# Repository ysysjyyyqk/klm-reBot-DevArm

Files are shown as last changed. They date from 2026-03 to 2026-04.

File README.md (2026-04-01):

# 🦾 reBot-DevArm: Open Source Robotic Arm for All Developers

<p align="center">
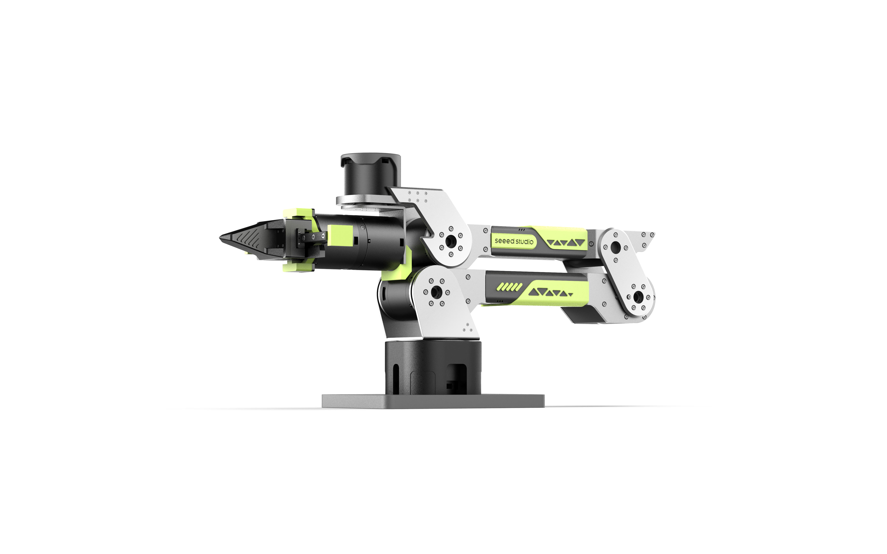
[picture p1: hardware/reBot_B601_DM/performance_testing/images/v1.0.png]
reBot-DevArm Banner
  
</p>

<p align="center">
    <!-- Replaced with CC BY-NC-SA 4.0 badge, explicitly indicating non-commercial use -->
    <a href="./LICENSE">
    
    </a>
    
    
    
    
</p>

<p align="center">
  <strong>100% Fully Open Source · Embodied AI · Hardware-Software Integration · Free for Personal/Education · Commercial Use Requires Authorization</strong>
</p>

<p align="center">
  <strong>
    <a href="./README_zh.md">简体中文</a> &nbsp;|&nbsp;
    <a href="./README.md">English</a> &nbsp;|&nbsp;
    <a href="./README_JP.md">日本語</a>&nbsp;|&nbsp;
    <a href="./README_Fr.md">français</a>&nbsp;|&nbsp;
    <a href="./README_es.md">Español</a>
  </strong>
</p>

<p align="center">
<a href="https://discord.gg/AbGuqJhDpQ">
    </a>
<a href="https://wiki.seeedstudio.com/robotics_page/">  
    </a>
</p>

## 📖 Introduction

**reBot-DevArm (reBot Arm B601 DM and reBot Arm B601 RS)** is a robotic arm project dedicated to lowering the barrier to learning Embodied AI. We focus on **"True Open Source"** — not just the code, we unreservedly open source everything:
- 🦾 **Two versions of the robotic arm**：We will provide all open-source files for two versions of the robotic arm with the same appearance: **Robostride** and **Damiao**.
- 🛠️ **Hardware Blueprints**: Source files for sheet metal parts and 3D printed parts.
- 🔩 **BOM List**: Detailed down to the specifications and purchase links for every single screw.
- 💻 **Software & Algorithms**: Python SDK, ROS1/2, Isaac Sim, LeRobot, etc.

## Build Your Own reBot Arm

- We offer five kit options:
  - **Arm Body Motor Kit**: Includes only motors and wiring harnesses for the robotic arm.
  - **Arm Body Structural Kit**: Includes only mechanical structural components.
  - **Gripper Complete Kit**: Includes motors, wiring harnesses and structural components for the gripper.
  - **Full Kit**: Includes the complete set of the robotic arm body and gripper.
  - **Pre‑assembled Robotic Arm**: Fully assembled finished robotic arm.

You may purchase the remaining parts from the SeeedStudio Store based on the components you already have (expected availability: April 15, 2026).

[You can leave your information here, and we will send you the limited pre-order link in advance.](https://forms.gle/1MwdVKUqkuGu3C7L7)

## Getting Your Own reBot Arm

- We offer five versions of kits
  - **Arm Body Motor kit** for the robotic arm including only motors and wiring harnesses.
  - **Arm Body structural kit** containing only mechanical structural components. 
  - **Arm Gripper Complete kit** Motor, wiring and structural components of Gripper. 
  - **Complete kit** with the robotic arm plus gripper. 
  - **Assembled Arm** Pre-assembled robotic arm.

  You may purchase the remaining parts from the SeeedStudio bazaar (ETA 04.15.2026) based on the materials you already have.

  You may leave your information here, and we will send you the limited pre-order link in advance.

## 🗺️ Roadmap & Status

We are committed to continuously maintaining and adapting to mainstream robot development ecosystems. Below is our current adaptation progress and planned release schedule:

### reBot Arm B601 DM
| Supported Ecosystem | Status | Description / Estimated Release Date | Related Documentation |
| :--- | :---: | :--- | :--- |
| **Basic Motor Usage** | ✅ Completed | Basic motion control and API encapsulation | [Damiao Technology](https://wiki.seeedstudio.com/cn/damiao_series/) |
| **Open-Sourcing of the New STEP 3D Structural Parts and BOM** | ✅ Completed | STEP files for all parts in the new version, parts BOM, and reference prices for all machined components | [reBot Arm B601-DM BOM](./hardware/reBot_B601_DM/readme.md) |
| **Reference for Real Machine Performance Testing** | 🚧 In Progress  | Performance Reference of Robotic Arm under Normal and Extreme Operating Conditions |[Performance Testing](./hardware/reBot_B601_DM/performance_testing/Performance_Testing.md) |
| **Assembly Video** | 🚧 In Progress | Ultra-detailed assembly steps and video | [Expected: 2026.04.10] |
| **ROS2 (Humble)** | 🚧 In Progress  | Core drivers have been completed, and MoveIt2 is currently being optimized | [Expected: 2026.04.10] |
| **Python SDK** | 🚧 In Progress  |  | [Expected: 2026.04.10] |
| **Pinocchio Integration** | 🚧 In Progress  | Adaptation to the Pinocchio framework, enabling forward/inverse kinematics and gravity compensation for the robotic arm | [Expected: 2026.04.10] |
| **Isaac Sim Simulation** | 🚧 In Progress  | Import USD models and enable simulated teleoperation | [Expected: 2026.04.20] |
| **LeRobot Integration** | 🚧 In Progress  | Adaptation to the Hugging Face LeRobot training framework | [Expected: 2026.04.30] |
| **Gradual Updates of the Latest Algorithms** | ⏳ Planned | Mainstream algorithms will be updated progressively | Ongoing |
| **Launch of a Series of Completely Free Courses** | ⏳ Planned | Mainstream algorithms will be updated progressively | Ongoing |

### reBot Arm B601 RS

| Supported Ecosystem | Status | Description / Estimated Release Date | Related Documentation |
| :--- | :---: | :--- | :--- |
| **Basic Motor Usage** | ✅ Completed | Basic motion control and API encapsulation | [Robstride](https://wiki.seeedstudio.com/cn/robstride_control/) |
| **Open-Sourcing of the New STEP 3D Structural Parts and BOM** | 🚧 In Progress | STEP files for all parts in the new version, parts BOM, and reference prices for all machined components | Expected [2026.04.31] |
| **Assembly Video** | 🚧 In Progress | Ultra-detailed assembly steps and video | [Expected 2026.05.10] |
| **ROS2 (Humble)** | ⏳ Planned | Core drivers have been completed, and MoveIt2 is currently being optimized | [Expected 2026.05] |
| **LeRobot Integration** | ⏳ Planned | Adaptation to the Hugging Face LeRobot training framework | [Expected 2026.05] |
| **Pinocchio Integration** | ⏳ Planned | Adaptation to the Pinocchio framework, enabling forward/inverse kinematics and gravity compensation for the robotic arm | [Expected 2026.05] |
| **Isaac Sim Simulation** | ⏳ Planned | Import USD models and enable simulated teleoperation | [Expected 2026.05] |
| **Gradual Updates of the Latest Algorithms** | ⏳ Planned | Mainstream algorithms will be updated progressively | Ongoing |
| **Launch of a Series of Completely Free Courses** | ⏳ Planned | Mainstream algorithms will be updated progressively | Ongoing |

---

### 🎓 Full-Stack Robotics Ecosystem
reBot-DevArm is not just a robotic arm, but a robotics learning community. We share the following general tutorials for free:

#### 🖥️ Edge Computing & Master Control
*    —— **AI Inference & Compute Core**
*    —— **General Linux Development Environment**
*    —— **Low-power Wireless Control Node**

#### 📡 Sensors & Peripherals
*   **🚗 Motors & Servos**: [Damiao / Gogo / Robstride / Mita / Feite / Fashion Star](https://wiki.seeedstudio.com/robotics_page/)
*   **👁️ Visual Perception**: [Depth Cameras / LiDAR / Vision Algorithms](https://wiki.seeedstudio.com/robotics_page/)
*   **👂 Auditory Interaction**: [ReSpeaker Mic Arrays / Speech Recognition](https://wiki.seeedstudio.com/ReSpeaker_Mic_Array_v2.0/)
*   **🧭 Motion & Attitude**: [IMU (6-axis/9-axis) / Gyroscopes / Magnetometers](https://wiki.seeedstudio.com/Sensor/IMU/)
*   **🤖 Comprehensive Kits**: [More Robotics Sensors & Driver Examples](https://wiki.seeedstudio.com/robotics_page/)

> 👉 **[Click to Enter Wiki Knowledge Base](https://wiki.seeedstudio.com/)** (All tutorials are free to view)

---

## ⚙️ Hardware Specifications

reBot-DevArm is designed for desktop Embodied AI applications, balancing payload capacity with flexibility.

| Parameter | reBot Arm B601-DM |
| :--- | :--- |
| **Recommended Continuous Payload** | Less than 1.5 kg within 70% of arm reach workspace |
| **Recommended Payload** | **1.5 kg** |
| **Max Reach** | **650 mm** |
| **Weight** | Approx. 4.5 kg |
| **Repeatability** | < 0.2 mm |
| **Degrees of Freedom (DOF)** | 6 DOF + 1 Gripper (Open source CAN servo gripper and joint motor gripper coming soon) |
| **Supported Platforms/Ecosystems** | ROS1, ROS2, LeRobot, Pinocchio, Isaac Sim, Python SDK |
| **Supply Voltage** | DC 24V |

## 🙌 References & Acknowledgments
The path of open source is never lonely. The birth of the reBot-DevArm project would not be possible without the full support of Seeed Studio, the global open source community, and excellent hardware partners. We pay our highest respects to the following projects and teams:

### 🌍 Ecosystem & Software Support
*   **[Seeed Studio](https://www.seeedstudio.com/)** - Providing comprehensive hardware supply chain and technical support.
*   **[Hugging Face LeRobot](https://github.com/huggingface/lerobot)** - An excellent end-to-end robot learning framework.
*   **[NVIDIA Isaac Sim](https://developer.nvidia.com/isaac/sim)** - A powerful robot simulation and synthetic data platform.

### ⚙️ Core Hardware Partners
Thanks to the following manufacturers for providing high-performance motor and actuator solutions:
*   **[Damiao Technology](https://www.damiaokeji.com/)**
*   **[Robstride](https://robstride.com/)**
*   **[Fashion Star](https://fashionrobo.com/)**

### 💡 Inspiration
This project is deeply inspired by the following excellent open source projects:
*   **[SO-ARM100](https://github.com/TheRobotStudio/SO-ARM100/tree/main)**
*   **[Mobile ALOHA](https://github.com/tonyzhaozh/aloha)**
*   **[Dummy-Robot (Zhihui Jun)](https://github.com/peng-zhihui/Dummy-Robot)**
*   **[OpenArm](https://openarm.dev/)**
*   **[I2RT](https://i2rt.com/)**
*   **[TRLC-DK1](https://github.com/robot-learning-co/trlc-dk1)**

### 🎃 Prototype Contributors
- **SeeedStudio AI Robotics Team's**: Yaohui Zhu (yaohui.zhu@seeed.cc)
- **SeeedStudio STU**: Wentao Dong
- **SeeedStudio STU**: Weiwei Xu
- **SeeedStudio Purchasing Department**: Fengqun Peng

### 👥 Contributors

## Our Top Contributors 
<p align="center"><a href="https://github.com/Seeed-Projects/reBot-DevArm/graphs/contributors">
  
</a></p>

*Coming soon... Welcome to submit PRs to become a contributor!*

## Star History

Star History Chart (https://www.star-history.com/#Seeed-Projects/reBot-DevArm&type=date&legend=top-left)

# reBot-DevArm Project License
Copyright (c) [2025] [Seeed Studio]

This work is licensed under the **Creative Commons Attribution-NonCommercial-ShareAlike 4.0 International License**.
To view a copy of this license, visit: http://creativecommons.org/licenses/by-nc-sa/4.0/

--------------------------------------------------------------------------------

## Rights and Restrictions Statement

The core purpose of this open-source project is to promote knowledge sharing and enable developers and enthusiasts to access and learn cutting-edge robotic arm technologies at minimal cost. We provide completely free and publicly available documentation and video tutorials to help users get started quickly, conduct in-depth research, and jointly promote the popularization and practical application of robotics.

### I. Non-Commercial Use Policy

All open-source content of this project is fully available for personal learning, research, and non-commercial use. Individual users are allowed to:

* View and study the project’s open-source documentation, code, and tutorials;
* Modify and debug the open-source content for personal learning and research purposes;
* Assemble robotic arms for personal use or conduct secondary development based on the open-source content for non-commercial purposes.

### II. Commercial Use Policy

We actively encourage and support developers, robotics enthusiasts, and third-party platforms to carry out secondary development based on the reBot robotic arm and promote real-world applications. The following outlines permitted and prohibited commercial activities:

#### (1) Permitted Commercial Activities

We respect every developer’s efforts and legitimate earnings. If you purchase the reBot B601 series robotic arm from Seeed and contribute your own work, you may commercialize the results of your efforts, including but not limited to:

* Developing application-oriented software systems and promoting or selling them commercially;
* Creating structured educational courses (online/offline) and offering paid training or knowledge services;
* Conducting offline education, training, and technology outreach activities worldwide;
* Other commercial activities that contribute to the open-source community, knowledge dissemination, and real-world application of robotics technology.

For the above compliant commercial activities, you are welcome to contact us. We will provide commercial authorization, implementation support, and promotional assistance. We may also publicly announce your authorization to help your project succeed.

#### (2) Prohibited Commercial Activities

It is prohibited to make minor modifications to this project’s product, replace IP, logos, or related identifiers, and sell it under a self-owned brand. Such actions do not constitute substantial technical innovation and do not benefit developer growth, the open-source community, or the project itself. These behaviors are considered violations, and we reserve the right to take action.

### III. Collaboration & Contact

We hope to collaborate with all developers and partners within a compliant framework to promote the maturity and deployment of the reBot robotic arm project. For individuals and organizations interested in bringing real-world robotic applications to life, we offer:

* Commercial licensing and intellectual property compliance support;
* Assistance in promoting project solutions;
* Custom development services for robotic arms and related solutions;
* Joint R&D and co-development opportunities.

If you are interested in commercial collaboration or have related needs, please feel free to contact us. Let’s work together to advance the adoption and industrialization of robotics technology.

## ☎ Contact Us
- **Open‑Source Progress & Technical Support**-Yaohui: yaohui.zhu@seeed.cc
- **Future Collaboration & Customization**-Elaine: elaine.wu@seeed.cc

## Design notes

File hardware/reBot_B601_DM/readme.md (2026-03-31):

# 🤖 reBot DevArm Open-Source Hardware Description

<p align="center">
  reBot-DevArm Banner
</p>

<p align="center">
  <strong>
    <a href="./readme_zh.md">简体中文</a> &nbsp;|&nbsp;
    <a href="./readme.md">English</a> &nbsp;|&nbsp;
    <a href="./readme_jp.md">日本語</a>&nbsp;|&nbsp;
    <a href="./readme_fr.md">français</a>&nbsp;|&nbsp;
    <a href="./readme_es.md">Español</a>
  </strong>
</p>

The current BOM is the component list for the **reBot Arm B601 DM** robotic arm, which uses the **Damiao 43 series motors**. Another version, the **reBot Arm B601 RS** robotic arm, uses **RobStride motors**. [Please see the list here](../reBot_B601_RS/README.md)

# 📦 File Structure

* `3D_Printed_Parts/`: STEP files for all 3D-printed parts.
* `Metal_Parts/`: STEP files for all metal machined parts.
* `Purchased_Parts/`: STEP files for all purchased parts.
* `reBot_B601_DM_v1.0_20260331.step`: Complete robotic arm assembly file.

# 📊 Bill of Materials (BOM)

> [!WARNING]
> Hereby declared: the published BOM does **not** represent the final version shipped by Seeed. This `v1.0` open-source version is intended to help developers reproduce the design themselves with the lowest possible cost, and therefore reduces some unnecessary detail-related expenses. The final version shipped by Seeed will include details that increase cost, such as laser-engraved anti-error markings on metal parts, replacement of some 3D-printed parts with metal parts for durability, clearance and machining precision adjustments based on the tolerances of metal processing factories (a balance between precision and cost), special customization of wire harnesses (for example, adding braided rope protection), and other detail optimizations. However, the structural configuration remains the same.

---

## 🖨️ 3D-Printed Parts

| Part Description | Image | File Name | Material | Quantity | Notes |
|---|---|---|---|---|---|
| Robotic arm base platform |  | `01_BASE_Plate.step` | Bambu ABS Black | 1 | 0.4 nozzle, 0.2 layer height, 30% infill |
| Robotic arm base |  | `01_BASE_Link.step` | Bambu ABS Black | 1 | 0.4 nozzle, 0.2 layer height, 30% infill |
| Upper arm left filler |  | `01_Upper_Arm_Fuller_L.step` | Bambu PLA Black and Green | 1 | 0.4 nozzle, 0.2 layer height, 15% infill |
| Upper arm right filler |  | `01_Upper_Arm_Fuller_R.step` | Bambu PLA Black and Green | 1 | 0.4 nozzle, 0.2 layer height, 15% infill |
| Upper arm middle filler |  | `01_Upper_Arm_Fuller_M.step` | Bambu ABS Black | 1 | 0.4 nozzle, 0.2 layer height, 30% infill |
| Upper arm horizontal limit block |  | `01_Upper_Arm_Limit.step` | Bambu ABS Black | 1 | 0.4 nozzle, 0.2 layer height, 30% infill |
| Robotic arm handle |  | `01_Arm_Handle.step` | Bambu ABS Black | 1 | 0.4 nozzle, 0.2 layer height, 30% infill |
| Forearm left filler |  | `01_Lower_Arm_Filler_L.step` | Bambu PLA Black and Green | 1 | 0.4 nozzle, 0.2 layer height, 15% infill |
| Forearm right filler |  | `01_Lower_Arm_Filler_R.step` | Bambu PLA Black and Green | 1 | 0.4 nozzle, 0.2 layer height, 15% infill |
| Forearm middle filler |  | `01_Lower_Arm_Filler_M.step` | Bambu ABS Black | 1 | 0.4 nozzle, 0.2 layer height, 30% infill |
| Upper arm decorative cover |  | `01_Upper_Arm_Cover.step` | Bambu PLA Green | 1 | 0.4 nozzle, 0.2 layer height, 15% infill |
| Forearm decorative cover |  | `01_Lower_Arm_Cover.step` | Bambu PLA Green | 1 | 0.4 nozzle, 0.2 layer height, 15% infill |
| Motor No. 5 protective cover |  | `01_Motor_Cover.step` | Bambu ABS Black | 1 | 0.4 nozzle, 0.2 layer height, 30% infill |
| Gripper horizontal limit |  | `01_Lower_Arm_Limit.step` | Bambu PLA Green | 1 | 0.4 nozzle, 0.2 layer height, 15% infill |
| Gripper slider filler bracket |  | `01-Rail-Bracket.step` | Bambu PLA Green | 1 | 0.4 nozzle, 0.2 layer height, 15% infill |
| Gripper |  | `01_Finger.step` | Bambu ABS Black | 2 | 0.4 nozzle, 0.2 layer height, 45% infill |
|  | `Reference price` | Average **50 $** |  |  | Price may vary slightly depending on printing material prices and factory printing time |

### 🧩 Printing Recommendations

- Layer height: 0.2 mm
- Nozzle: 0.4 mm
- Supports: add as needed
- Materials: parts that need to withstand heat and certain force use ABS material with 30% to 80% infill, and may also be changed to nylon / carbon-fiber-reinforced materials; appearance/decorative parts use PLA with 15% infill.
- Recommended materials for load-bearing parts:

---

## 🔩 Metal Machined Parts

> [!WARNING]
> Some parts that can be replaced with 3D printing are indicated in the notes below, which can further greatly reduce costs.

| Part Description | Image | File Name | Material | Quantity | Manufacturing Process | Notes |
|---|---|---|---|---|---|---|
| Motor 1 bearing mounting position |  | `02_Base_Motor_Shim.step` | Aluminum Alloy 5052 | 1 | CNC | Can be replaced with 3D-printed ABS with increased infill to reduce cost |
| Motor 1 rotating shaft |  | `02_Arm_Yaw_Limit.step` | Aluminum Alloy 5052 | 1 | CNC | Adds yaw angle motion limit |
| Front spacer for motors 2-5 |  | `02_Motor_Front_Spacer.step` | Aluminum Alloy 5052 | 4 | CNC | Can be replaced with 3D-printed ABS, 30% infill, to reduce cost |
| Rear spacer for motors 2-4 |  | `02_Motor_Back_Spacer.step` | Aluminum Alloy 5052 | 3 | CNC |  |
| Rear flange for motors 2-4 |  | `02_FLANGE.step` | Aluminum Alloy 5052 | 3 | CNC |  |
| Wrist motor 5 base |  | `02_Wrist_Bracket.step` | Aluminum Alloy 5052 | 1 | CNC |  |
| Gripper connector A |  | `02_Gripper_Connector_A.step` | Aluminum Alloy 5052 | 1 | CNC |  |
| Gripper connector B |  | `02_Gripper_Connector_B.step` | Aluminum Alloy 5052 | 1 | CNC |  |
| Gripper slider metal bracket |  | `02_Slider_Bracket.step` | Aluminum Alloy 5052 | 1 | CNC | Can be replaced with 3D-printed ABS with increased infill to reduce cost, but not recommended for long-term use |
| Slider and gripper connector |  | `02_Slider_Extension.step` | Aluminum Alloy 5052 | 2 | CNC |  |
| Upper and lower arm joint connector left |  | `02_Lower_Upper_Link_L.step` | Aluminum Alloy 5052 | 1 | CNC |  |
| Upper and lower arm joint connector right |  | `02_Lower_Upper_Link_R.step` | Aluminum Alloy 5052 | 1 | CNC |  |
| Forearm and wrist joint connector left |  | `02_Lower_Wrist_Link_L.step` | Aluminum Alloy 5052 | 1 | CNC |  |
| Forearm and wrist joint connector right |  | `02_Lower_Wrist_Link_R.step` | Aluminum Alloy 5052 | 1 | CNC |  |
| Gear connector |  | `02_Gear_Connector.step` | Aluminum Alloy 5052 | 1 | CNC | For low load, 3D-printed ABS with 80% infill can be used to reduce cost; for high load, CNC metal machining is recommended |
| Rack |  | `02_Rack.step` | Aluminum Alloy 5052 | 2 | CNC |  |
| Link 1 |  | `03-Link1.step` | Aluminum Alloy 5052 | 1 | CNC + Sheet Metal |  |
| Link 2 |  | `03-Link2.step` | Aluminum Alloy 5052 | 2 | CNC + Sheet Metal |  |
| Link 3 left |  | `03-Link3_L.step` | Aluminum Alloy 5052 | 1 | CNC + Sheet Metal |  |
| Link 3 right |  | `03-Link3_R.step` | Aluminum Alloy 5052 | 1 | CNC + Sheet Metal |  |
| Link 5 |  | `03-Link5.step` | Aluminum Alloy 5052 | 1 | CNC + Sheet Metal |  |
| Multiple market reference price |  | Average **250 $** |  |  |  | Price may vary slightly due to fluctuations in aluminum 5052 cost, machining precision requirements, factory lead time, etc. |

### 🧩 Machining Instructions

- Critical dimensional tolerance: ±0.02 mm, GB/T1840-M;
- Surface treatment: anodizing / sandblasting
- Mating parts are recommended to use H7 / interference fit

---

## 🛒 Purchased Parts (Standard Parts)

> [!WARNING]
> Since everyone will need to assemble and tighten the screws themselves, standard hex socket screws have been selected. After prolonged operation, the screws may loosen, which will affect the precision of the robotic arm. For this reason, you are required to purchase additional hot melt glue to perform thread locking on the screws at each joint.

If you have a power drill or similar tools, you may choose to buy lock washers or thread-locking screws instead. However, **it is extremely important** that you use the lowest torque setting when using an electric screwdriver to avoid thread stripping, which will result in irreversible damage.

| Name | Specification / Model | Quantity | Reference Price | Notes |
|---|---|---|---|---|
| Brushless motor | DM4310(V4) | 4 | 120 $/unit | [SeeedStudio](https://www.seeedstudio.com/DIP-Servo-Motor-24V-120RPM-Brushless-98-9mm-4P-L56-W56-H46mm-p-6660.html) |
| Brushless motor | DM4340P(V4) | 3 | 175 $/unit |  [SeeedStudio](https://www.seeedstudio.com/DM4340P-Actuator-p-6663.html)  |
| CAN-USB driver board |  | 1 | 15 $/unit | [SeeedStudio](https://www.seeedstudio.com/DM-CAN-USB-Driver-Borad-p-6706.html) |
| Bearing | 6707ZZ | 1 | 13 $/unit | [Amazong](https://www.amazon.com/uxcell-35x44x5mm-Shielded-Precision-Lubricated/dp/B0D6WBMW3F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) |
| Bearing | 6803ZZ | 3 | 13 $/unit | [Amazong](https://www.amazon.com/uxcell-17x26x5mm-Shielded-Precision-Lubricated/dp/B0D54JSWBZ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) |
| Bearing | AXK5578 | 1 | 12 $/unit | [Amazong](https://www.amazon.com/PZRT-AXK5578-Thrust-Bearings-Washers/dp/B0B3M3RZGW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) |
| Linear rail | MGN9-170mm | 1 | 23 $/unit | [Amazong](https://www.amazon.com/uxcell-Sliding-Carriage-Bearing-Printers/dp/B0D54L45WM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) |
| Slider block | MGN9 | 2 | 10 $/unit | [Amazong](https://www.amazon.com/uxcell-Bearing-Sliding-Carriage-Anti-Fall/dp/B0D9QBQDKB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) |
| Gear | Module 1, boss type, 16 teeth, 6 mm bore | 1 | 44$/unit | [Amazong](https://www.amazon.com/Module-15-Teeth-Finished-Perforation/dp/B0GDSR1LKM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)  |
| Silicone pad | 30*9*2mm | 1 | 10 $ | [Amazong](https://www.amazon.com/Self-Adhesive-Anti-Sliding-Anti-Scratch-Protectors-Appliances/dp/B0F9KVYXFZ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) |
| Copper standoff | M4x50mm | 4 | 8 $ | [Amazong](https://www.amazon.com/Female-Standoff-Quadcopter-Computer-Circuit/dp/B09V2CYDMG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) |
| Screw | M3*22mm screw | Several |  | [Amazong](https://www.amazon.com/METERXITY-50-Pack-Stainless-Threaded-Fasteners/dp/B0FLYG7WZ7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)  |
| Screw | M4*16mm screw | Several |  | [Amazong](amazon.com/BNUOK-120pcs-Stainless-Threads-Spanner/dp/B0DYNFFB7Q/ref=sr_1_9?crid=W94HLTGLCH57&dib=eyJ2IjoiMSJ9.jg07IMpJdHhW8vR9Ewx53UNnQs_QkpENya6ZqIQWoB6rsXjPLmfWMgAytRy7neNPJJHQzVyP9H7FO5sm9KN9I34nKUQsLRZAG48Rs2rSHwlh2mpA2IPlezHLRlvLN49IIbiHgk5Y63iPwAaxKT27sG3dhyXpf-EABXWIlgUu0FBQ3IIA5kiQDccrsIPN06nR6XBFnNeTu1ogpvhiaZsK7R-VRXcFAsrQvOc4tnzXLlTSM68gR8hBmGYZtQUoOJrRo93U1xfGf7kODnnOqUBWI3VhQIMgnl8Rtt4pl3H7IK0._jHfn0N3UQ0z_FJlv4C8jBXiadkqdO-IHWJzQ3xlm0w&dib_tag=se&keywords=M4*16mm+screw&qid=1774772422&s=industrial&sprefix=m4+16mm+screw%2Cindustrial%2C364&sr=1-9)  |
| Screw | M3*8mm set screw | 5 | 5$ | [Amazong](https://www.amazon.com/Headless-Internal-Stainless-Concave-External/dp/B0D8TGXG9D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)  |
| Screw | M3*22mm countersunk screw | Several |  |  [Amazong](https://www.amazon.com/Countersunk-DIN7991-Stainless-Threaded-Fasteners/dp/B0CG1PV6SH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) |
| Screw | M3*8mm countersunk screw | Several |  | [Amazong](https://www.amazon.com/Countersunk-DIN7991-Stainless-Threaded-Fasteners/dp/B0CG1PV6SH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)  |
| Screw | M3*16mm countersunk screw | Several |  |[Amazong](https://www.amazon.com/Countersunk-DIN7991-Stainless-Threaded-Fasteners/dp/B0CG1PV6SH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) |
| Screw | M3*12mm self-tapping screw | Several |  | [Amazong](https://www.amazon.com/Countersunk-DIN7991-Stainless-Threaded-Fasteners/dp/B0CG1PV6SH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)  |
| Dowel pin | M4*8mm | Several |  | [Amazong](https://www.amazon.com/Countersunk-DIN7991-Stainless-Threaded-Fasteners/dp/B0CG1PV6SH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)  |
| Dowel pin | M4*12mm | Several |  | [Amazong](https://www.amazon.com/Countersunk-DIN7991-Stainless-Threaded-Fasteners/dp/B0CG1PV6SH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)  |
| Screwdriver set | Hex key set | 1 | 16$  | [Amazong](amazon.com/Amazon-Basics-Ratcheting-Electronics-Screwdriver/dp/B07V4TFWFZ/ref=sr_1_2?crid=ADAY70RZDSLN&dib=eyJ2IjoiMSJ9.jcLL4o6IXTnPlPfTTzbCZCBuZx2sLkvdUQCwlL58aq__GOyLxVPnwLI0mvGptba_HeVz6ctLQ_ziQw56BMDH9IOaw-4PVJGMktQM74mWficwggm3ckDGyAH-agN_zkB3K0_W-wrS56jfcMYFbZSWhWxr-iSOC4sdXwMGlt4rYGtenyn9yAFYBIHqjU2El5_OAKuspsrF0yQvfyfQPQHs46SClWN8zlSemGVZRuVSU26f0f9yApF6BfWHANKNNhT0Mfb6bQ8oM2XUMvwaazrrKoHeTARuoflVaVZvMU776bs.r8gy_gMINEy0qy4JyK--z-IbPZEv-SWeMGohOOE7M60&dib_tag=se&keywords=Screwdriver+set&qid=1774772499&s=industrial&sprefix=screwdriver+set+%2Cindustrial%2C374&sr=1-2)  |
| Custom required | XT30 2+2 350mm | 2 | 4 $/cable | Both ends angled |
| Custom required | XT30 2+2 350mm | 1 | 4 $/cable | One angled end and one straight end |
| Custom required | XT30 2+2 200mm | 3 | 4 $/cable | Both ends angled |
| Custom required | XT30 2+2 200mm | 1 | 3 $/cable | Both ends straight |
| Woodworking clamp | 6-inch G clamp | 2 | 20 $/unit | [Amazong](https://www.amazon.com/gp/aw/d/B092J1YW2M/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) |
| Power supply | 24V 14.6A | 1 | 30$ | [Amazong](https://www.amazon.com/MEAN-WELL-LRS-350-24-350-4W-Switchable/dp/B013ETVO12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) |
| Power Cable | 12AWG | 1 | 30 $ | [Amazong](https://www.amazon.com/Pinfox-Universal-Appliance-Replacement-Pigtail/dp/B0F5PW5SJG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) |
| Power Cable | XT30 16awg | 1 | 9 $ | [Amazong](https://www.amazon.com/RioRand-Connector-Pigtail-Silicone-Aircraft/dp/B0FY2ZCR83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) |

---

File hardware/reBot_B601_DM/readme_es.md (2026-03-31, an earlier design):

# 🤖 Descripción del hardware de código abierto reBot DevArm

<p align="center">
  Banner de reBot-DevArm
</p>
<p align="center">
  <strong>
    <a href="./readme_zh.md">简体中文</a> &nbsp;|&nbsp;
    <a href="./readme.md">English</a> &nbsp;|&nbsp;
    <a href="./readme_jp.md">日本語</a>&nbsp;|&nbsp;
    <a href="./readme_fr.md">français</a>&nbsp;|&nbsp;
    <a href="./readme_es.md">Español</a>
  </strong>
</p>

La BOM actual es la lista de componentes del brazo robótico **reBot Arm B601 DM**, que utiliza los **motores de la serie Damiao 43**. Otra versión, el brazo robótico **reBot Arm B601 RS**, utiliza **motores RobStride**. [Consulte la lista aquí](../reBot_B601_RS/README_zh.md)

# 📦 Estructura de archivos

* `3D_Printed_Parts/`: archivos STEP de todas las piezas impresas en 3D.
* `Metal_Parts/`: archivos STEP de todas las piezas metálicas mecanizadas.
* `Purchased_Parts/`: archivos STEP de todas las piezas compradas.
* `reBot_B601_DM_v1.0_20260331.step`: archivo de ensamblaje completo del brazo robótico.

# 📊 Lista de materiales (BOM)

> [!WARNING]
> Por la presente se declara: la BOM publicada **no** representa la versión final enviada por Seeed. Esta versión de código abierto `v1.0` está destinada a ayudar a los desarrolladores a reproducir el diseño por sí mismos con el menor costo posible y, por lo tanto, reduce algunos gastos innecesarios relacionados con detalles. La versión final enviada por Seeed incluirá detalles que aumentan el costo, como marcas antierrores grabadas con láser en las piezas metálicas, reemplazo de algunas piezas impresas en 3D por piezas metálicas para mayor durabilidad, ajustes de holgura y precisión de mecanizado basados en las tolerancias de las fábricas de procesamiento de metal (un equilibrio entre precisión y costo), personalización especial del arnés de cables (por ejemplo, añadiendo protección con malla trenzada) y otras optimizaciones de detalle. Sin embargo, la configuración estructural sigue siendo la misma.

---

## 🖨️ Piezas impresas en 3D

| Descripción de la pieza | Image | File Name | Material | Quantity | Notes |
|---|---|---|---|---|---|
| Plataforma base del brazo robótico |  | `01_BASE_Plate.step` | Bambu ABS Black | 1 | boquilla 0.4, altura de capa 0.2, relleno 30% |
| Base del brazo robótico |  | `01_BASE_Link.step` | Bambu ABS Black | 1 | boquilla 0.4, altura de capa 0.2, relleno 30% |
| Relleno izquierdo del brazo superior |  | `01_Upper_Arm_Fuller_L.step` | Bambu PLA Black and Green | 1 | boquilla 0.4, altura de capa 0.2, relleno 15% |
| Relleno derecho del brazo superior |  | `01_Upper_Arm_Fuller_R.step` | Bambu PLA Black and Green | 1 | boquilla 0.4, altura de capa 0.2, relleno 15% |
| Relleno central del brazo superior |  | `01_Upper_Arm_Fuller_M.step` | Bambu ABS Black | 1 | boquilla 0.4, altura de capa 0.2, relleno 30% |
| Tope horizontal del brazo superior |  | `01_Upper_Arm_Limit.step` | Bambu ABS Black | 1 | boquilla 0.4, altura de capa 0.2, relleno 30% |
| Asa del brazo robótico |  | `01_Arm_Handle.step` | Bambu ABS Black | 1 | boquilla 0.4, altura de capa 0.2, relleno 30% |
| Relleno izquierdo del antebrazo |  | `01_Lower_Arm_Filler_L.step` | Bambu PLA Black and Green | 1 | boquilla 0.4, altura de capa 0.2, relleno 15% |
| Relleno derecho del antebrazo |  | `01_Lower_Arm_Filler_R.step` | Bambu PLA Black and Green | 1 | boquilla 0.4, altura de capa 0.2, relleno 15% |
| Relleno central del antebrazo |  | `01_Lower_Arm_Filler_M.step` | Bambu ABS Black | 1 | boquilla 0.4, altura de capa 0.2, relleno 30% |
| Cubierta decorativa del brazo superior |  | `01_Upper_Arm_Cover.step` | Bambu PLA Green | 1 | boquilla 0.4, altura de capa 0.2, relleno 15% |
| Cubierta decorativa del antebrazo |  | `01_Lower_Arm_Cover.step` | Bambu PLA Green | 1 | boquilla 0.4, altura de capa 0.2, relleno 15% |
| Cubierta protectora del motor n.º 5 |  | `01_Motor_Cover.step` | Bambu ABS Black | 1 | boquilla 0.4, altura de capa 0.2, relleno 30% |
| Tope horizontal de la pinza |  | `01_Lower_Arm_Limit.step` | Bambu PLA Green | 1 | boquilla 0.4, altura de capa 0.2, relleno 15% |
| Soporte de relleno del deslizador de la pinza |  | `01-Rail-Bracket.step` | Bambu PLA Green | 1 | boquilla 0.4, altura de capa 0.2, relleno 15% |
| Pinza |  | `01_Finger.step` | Bambu ABS Black | 2 | boquilla 0.4, altura de capa 0.2, relleno 45% |
|  | `Reference price` | Promedio **50 $** |  |  | El precio puede variar ligeramente según el precio del material de impresión y el tiempo de impresión de la fábrica |

### 🧩 Recomendaciones de impresión

- Altura de capa: 0.2 mm
- Boquilla: 0.4 mm
- Soportes: añadir según sea necesario
- Materiales: las piezas que necesitan soportar calor y cierta fuerza utilizan material ABS con un relleno del 30% al 80%, y también pueden cambiarse a materiales de nailon / reforzados con fibra de carbono; las piezas de apariencia/decorativas utilizan PLA con un relleno del 15%.
- Materiales recomendados para piezas portantes:

---

## 🔩 Piezas metálicas mecanizadas

> [!WARNING]
> Algunas piezas que pueden sustituirse por impresión 3D se indican en las notas a continuación, lo que puede reducir aún más considerablemente los costos.

| Descripción de la pieza | Image | File Name | Material | Quantity | Manufacturing Process | Notes |
|---|---|---|---|---|---|---|
| Posición de montaje del rodamiento del motor 1 |  | `02_Base_Motor_Shim.step` | Aleación de aluminio 5052 | 1 | CNC | Puede sustituirse por ABS impreso en 3D con mayor relleno para reducir costos |
| Eje giratorio del motor 1 |  | `02_Arm_Yaw_Limit.step` | Aleación de aluminio 5052 | 1 | CNC | Añade límite de movimiento del ángulo de guiñada |
| Espaciador frontal para los motores 2-5 |  | `02_Motor_Front_Spacer.step` | Aleación de aluminio 5052 | 4 | CNC | Puede sustituirse por ABS impreso en 3D, relleno 30%, para reducir costos |
| Espaciador trasero para los motores 2-4 |  | `02_Motor_Back_Spacer.step` | Aleación de aluminio 5052 | 3 | CNC |  |
| Brida trasera para los motores 2-4 |  | `02_FLANGE.step` | Aleación de aluminio 5052 | 3 | CNC |  |
| Base del motor de muñeca 5 |  | `02_Wrist_Bracket.step` | Aleación de aluminio 5052 | 1 | CNC |  |
| Conector de pinza A |  | `02_Gripper_Connector_A.step` | Aleación de aluminio 5052 | 1 | CNC |  |
| Conector de pinza B |  | `02_Gripper_Connector_B.step` | Aleación de aluminio 5052 | 1 | CNC |  |
| Soporte metálico del deslizador de la pinza |  | `02_Slider_Bracket.step` | Aleación de aluminio 5052 | 1 | CNC | Puede sustituirse por ABS impreso en 3D con mayor relleno para reducir costos, pero no se recomienda para uso a largo plazo |
| Deslizador y conector de pinza |  | `02_Slider_Extension.step` | Aleación de aluminio 5052 | 2 | CNC |  |
| Conector izquierdo de la articulación entre brazo superior e inferior |  | `02_Lower_Upper_Link_L.step` | Aleación de aluminio 5052 | 1 | CNC |  |
| Conector derecho de la articulación entre brazo superior e inferior |  | `02_Lower_Upper_Link_R.step` | Aleación de aluminio 5052 | 1 | CNC |  |
| Conector izquierdo de la articulación entre antebrazo y muñeca |  | `02_Lower_Wrist_Link_L.step` | Aleación de aluminio 5052 | 1 | CNC |  |
| Conector derecho de la articulación entre antebrazo y muñeca |  | `02_Lower_Wrist_Link_R.step` | Aleación de aluminio 5052 | 1 | CNC |  |
| Conector de engranaje |  | `02_Gear_Connector.step` | Aleación de aluminio 5052 | 1 | CNC | Para baja carga, puede utilizarse ABS impreso en 3D con relleno del 80% para reducir costos; para alta carga, se recomienda mecanizado CNC en metal |
| Cremallera |  | `02_Rack.step` | Aleación de aluminio 5052 | 2 | CNC |  |
| Link 1 |  | `03-Link1.step` | Aleación de aluminio 5052 | 1 | CNC + chapa metálica |  |
| Link 2 |  | `03-Link2.step` | Aleación de aluminio 5052 | 2 | CNC + chapa metálica |  |
| Link 3 izquierdo |  | `03-Link3_L.step` | Aleación de aluminio 5052 | 1 | CNC + chapa metálica |  |
| Link 3 derecho |  | `03-Link3_R.step` | Aleación de aluminio 5052 | 1 | CNC + chapa metálica |  |
| Link 5 |  | `03-Link5.step` | Aleación de aluminio 5052 | 1 | CNC + chapa metálica |  |
| Precio de referencia de mercado múltiple |  | Promedio **250 $** |  |  |  | El precio puede variar ligeramente debido a las fluctuaciones del costo del aluminio 5052, los requisitos de precisión de mecanizado, el plazo de entrega de la fábrica, etc. |

### 🧩 Instrucciones de mecanizado

- Tolerancia dimensional crítica: ±0.02 mm, GB/T1840-M;
- Tratamiento superficial: anodizado / arenado
- Se recomienda usar H7 / ajuste por interferencia en las piezas de acoplamiento

---

## 🛒 Piezas compradas (piezas estándar)

> [!WARNING]
> Dado que todos tendrán que armar y atornillar por su cuenta, se han seleccionado tornillos hexagonales internos estándar. Después de un funcionamiento prolongado, los tornillos pueden aflojarse y afectar la precisión del brazo robótico.
Por ello, es necesario comprar adicionalmente pegamento termofusible para realizar un tratamiento antiflojamiento en los tornillos de cada articulación. Si disponen de taladro eléctrico u otras herramientas, pueden adquirir tornillos antiflojamiento. Sin embargo, es muy importante usar la potencia mínima con el destornillador eléctrico para evitar dañar la rosca y causar pérdidas irreversibles.

| Name | Specification / Model | Quantity | Reference Price | Notes |
|---|---|---|---|---|
| Motor sin escobillas | DM4310(V4) | 4 | 120 $/unit | [SeeedStudio](https://www.seeedstudio.com/DIP-Servo-Motor-24V-120RPM-Brushless-98-9mm-4P-L56-W56-H46mm-p-6660.html) |
| Motor sin escobillas | DM4340P(V4) | 3 | 175 $/unit |  [SeeedStudio](https://www.seeedstudio.com/DM4340P-Actuator-p-6663.html)  |
| Placa controladora CAN-USB |  | 1 | 15 $/unit | [SeeedStudio](https://www.seeedstudio.com/DM-CAN-USB-Driver-Borad-p-6706.html) |
| Rodamiento | 6707ZZ | 1 | 13 $/unit | [Amazong](https://www.amazon.com/uxcell-35x44x5mm-Shielded-Precision-Lubricated/dp/B0D6WBMW3F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) |
| Rodamiento | 6803ZZ | 3 | 13 $/unit | [Amazong](https://www.amazon.com/uxcell-17x26x5mm-Shielded-Precision-Lubricated/dp/B0D54JSWBZ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) |
| Rodamiento | AXK5578 | 1 | 12 $/unit | [Amazong](https://www.amazon.com/PZRT-AXK5578-Thrust-Bearings-Washers/dp/B0B3M3RZGW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) |
| Riel lineal | MGN9-170mm | 1 | 23 $/unit | [Amazong](https://www.amazon.com/uxcell-Sliding-Carriage-Bearing-Printers/dp/B0D54L45WM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) |
| Bloque deslizante | MGN9 | 2 | 10 $/unit | [Amazong](https://www.amazon.com/uxcell-Bearing-Sliding-Carriage-Anti-Fall/dp/B0D9QBQDKB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) |
| Engranaje | Módulo 1, tipo cubo, 16 dientes, agujero de 6 mm | 1 | 44$/unit | [Amazong](https://www.amazon.com/Module-15-Teeth-Finished-Perforation/dp/B0GDSR1LKM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)  |
| Almohadilla de silicona | 30*9*2mm | 1 | 10 $ | [Amazong](https://www.amazon.com/Self-Adhesive-Anti-Sliding-Anti-Scratch-Protectors-Appliances/dp/B0F9KVYXFZ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) |
| Separador de cobre | M4x50mm | 4 | 8 $ | [Amazong](https://www.amazon.com/Female-Standoff-Quadcopter-Computer-Circuit/dp/B09V2CYDMG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) |
| Tornillo | Tornillo M3*22mm | Several |  | [Amazong](https://www.amazon.com/METERXITY-50-Pack-Stainless-Threaded-Fasteners/dp/B0FLYG7WZ7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)  |
| Tornillo | Tornillo M4*16mm | Several |  | [Amazong](amazon.com/BNUOK-120pcs-Stainless-Threads-Spanner/dp/B0DYNFFB7Q/ref=sr_1_9?crid=W94HLTGLCH57&dib=eyJ2IjoiMSJ9.jg07IMpJdHhW8vR9Ewx53UNnQs_QkpENya6ZqIQWoB6rsXjPLmfWMgAytRy7neNPJJHQzVyP9H7FO5sm9KN9I34nKUQsLRZAG48Rs2rSHwlh2mpA2IPlezHLRlvLN49IIbiHgk5Y63iPwAaxKT27sG3dhyXpf-EABXWIlgUu0FBQ3IIA5kiQDccrsIPN06nR6XBFnNeTu1ogpvhiaZsK7R-VRXcFAsrQvOc4tnzXLlTSM68gR8hBmGYZtQUoOJrRo93U1xfGf7kODnnOqUBWI3VhQIMgnl8Rtt4pl3H7IK0._jHfn0N3UQ0z_FJlv4C8jBXiadkqdO-IHWJzQ3xlm0w&dib_tag=se&keywords=M4*16mm+screw&qid=1774772422&s=industrial&sprefix=m4+16mm+screw%2Cindustrial%2C364&sr=1-9)  |
| Tornillo | Tornillo prisionero M3*8mm | 5 | 5$ | [Amazong](https://www.amazon.com/Headless-Internal-Stainless-Concave-External/dp/B0D8TGXG9D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)  |
| Tornillo | Tornillo avellanado M3*22mm | Several |  |  [Amazong](https://www.amazon.com/Countersunk-DIN7991-Stainless-Threaded-Fasteners/dp/B0CG1PV6SH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) |
| Tornillo | Tornillo avellanado M3*8mm | Several |  | [Amazong](https://www.amazon.com/Countersunk-DIN7991-Stainless-Threaded-Fasteners/dp/B0CG1PV6SH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)  |
| Tornillo | Tornillo avellanado M3*16mm | Several |  |[Amazong](https://www.amazon.com/Countersunk-DIN7991-Stainless-Threaded-Fasteners/dp/B0CG1PV6SH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) |
| Tornillo | Tornillo autorroscante M3*12mm | Several |  | [Amazong](https://www.amazon.com/Countersunk-DIN7991-Stainless-Threaded-Fasteners/dp/B0CG1PV6SH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)  |
| Pasador cilíndrico | M4*8mm | Several |  | [Amazong](https://www.amazon.com/Countersunk-DIN7991-Stainless-Threaded-Fasteners/dp/B0CG1PV6SH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)  |
| Pasador cilíndrico | M4*12mm | Several |  | [Amazong](https://www.amazon.com/Countersunk-DIN7991-Stainless-Threaded-Fasteners/dp/B0CG1PV6SH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)  |
| Juego de destornilladores | Juego de llaves hexagonales | 1 | 16$  | [Amazong](amazon.com/Amazon-Basics-Ratcheting-Electronics-Screwdriver/dp/B07V4TFWFZ/ref=sr_1_2?crid=ADAY70RZDSLN&dib=eyJ2IjoiMSJ9.jcLL4o6IXTnPlPfTTzbCZCBuZx2sLkvdUQCwlL58aq__GOyLxVPnwLI0mvGptba_HeVz6ctLQ_ziQw56BMDH9IOaw-4PVJGMktQM74mWficwggm3ckDGyAH-agN_zkB3K0_W-wrS56jfcMYFbZSWhWxr-iSOC4sdXwMGlt4rYGtenyn9yAFYBIHqjU2El5_OAKuspsrF0yQvfyfQPQHs46SClWN8zlSemGVZRuVSU26f0f9yApF6BfWHANKNNhT0Mfb6bQ8oM2XUMvwaazrrKoHeTARuoflVaVZvMU776bs.r8gy_gMINEy0qy4JyK--z-IbPZEv-SWeMGohOOE7M60&dib_tag=se&keywords=Screwdriver+set&qid=1774772499&s=industrial&sprefix=screwdriver+set+%2Cindustrial%2C374&sr=1-2)  |
| Requerido personalizado | XT30 2+2 350mm | 2 | 4 $/cable | Ambos extremos en ángulo |
| Requerido personalizado | XT30 2+2 350mm | 1 | 4 $/cable | Un extremo en ángulo y un extremo recto |
| Requerido personalizado | XT30 2+2 200mm | 3 | 4 $/cable | Ambos extremos en ángulo |
| Requerido personalizado | XT30 2+2 200mm | 1 | 3 $/cable | Ambos extremos rectos |
| Sargento para carpintería | Sargento tipo G de 6 pulgadas | 2 | 20 $/unit | [Amazong](https://www.amazon.com/gp/aw/d/B092J1YW2M/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) |
| Fuente de alimentación | 24V 14.6A | 1 | 30$ | [Amazong](https://www.amazon.com/MEAN-WELL-LRS-350-24-350-4W-Switchable/dp/B013ETVO12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) |
| Cable de alimentación | 12AWG | 1 | 30 $ | [Amazong](https://www.amazon.com/Pinfox-Universal-Appliance-Replacement-Pigtail/dp/B0F5PW5SJG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) |
| Cable de alimentación | XT30 16awg | 1 | 9 $ | [Amazong](https://www.amazon.com/RioRand-Connector-Pigtail-Silicone-Aircraft/dp/B0FY2ZCR83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) |

---

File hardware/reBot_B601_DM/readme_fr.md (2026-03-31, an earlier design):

# 🤖 Description du matériel open-source du bras reBot DevArm

<p align="center">
  Bannière reBot-DevArm
</p>
<p align="center">
  <strong>
    <a href="./readme_zh.md">简体中文</a> &nbsp;|&nbsp;
    <a href="./readme.md">English</a> &nbsp;|&nbsp;
    <a href="./readme_jp.md">日本語</a>&nbsp;|&nbsp;
    <a href="./readme_fr.md">français</a>&nbsp;|&nbsp;
    <a href="./readme_es.md">Español</a>
  </strong>
</p>

La nomenclature actuelle (BOM) est la liste des composants du bras robotique **reBot Arm B601 DM**, qui utilise les **moteurs de la série Damiao 43**. Une autre version, le bras robotique **reBot Arm B601 RS**, utilise des **moteurs RobStride**. [Veuillez consulter la liste ici](../reBot_B601_RS/README.md)

# 📦 Structure des fichiers

* `3D_Printed_Parts/` : fichiers STEP de toutes les pièces imprimées en 3D.
* `Metal_Parts/` : fichiers STEP de toutes les pièces métalliques usinées.
* `Purchased_Parts/` : fichiers STEP de toutes les pièces achetées.
* `reBot_B601_DM_v1.0_20260331.step` : fichier d’assemblage complet du bras robotique.

# 📊 Nomenclature (BOM)

> [!WARNING]
> Il est déclaré par la présente : la nomenclature (BOM) publiée **ne représente pas** la version finale expédiée par Seeed. Cette version open-source `v1.0` est destinée à aider les développeurs à reproduire eux-mêmes la conception au coût le plus bas possible, et réduit donc certaines dépenses inutiles liées aux détails. La version finale expédiée par Seeed inclura des détails qui augmentent le coût, tels que des marquages anti-erreur gravés au laser sur les pièces métalliques, le remplacement de certaines pièces imprimées en 3D par des pièces métalliques pour une meilleure durabilité, des ajustements de jeu et de précision d’usinage basés sur les tolérances des usines de traitement du métal (un équilibre entre précision et coût), une personnalisation spéciale des faisceaux de câbles (par exemple, l’ajout d’une protection par gaine tressée), ainsi que d’autres optimisations de détail. Cependant, la configuration structurelle reste la même.

---

## 🖨️ Pièces imprimées en 3D

| Description de la pièce | Image | Nom du fichier | Matériau | Quantité | Remarques |
| --- | --- | --- | --- | --- | --- |
| Plateforme de base du bras robotique |  | `01_BASE_Plate.step` | Bambu ABS Noir | 1 | buse 0,4, hauteur de couche 0,2, remplissage 30 % |
| Base du bras robotique |  | `01_BASE_Link.step` | Bambu ABS Noir | 1 | buse 0,4, hauteur de couche 0,2, remplissage 30 % |
| Remplissage gauche du bras supérieur |  | `01_Upper_Arm_Fuller_L.step` | Bambu PLA Noir et Vert | 1 | buse 0,4, hauteur de couche 0,2, remplissage 15 % |
| Remplissage droit du bras supérieur |  | `01_Upper_Arm_Fuller_R.step` | Bambu PLA Noir et Vert | 1 | buse 0,4, hauteur de couche 0,2, remplissage 15 % |
| Remplissage central du bras supérieur |  | `01_Upper_Arm_Fuller_M.step` | Bambu ABS Noir | 1 | buse 0,4, hauteur de couche 0,2, remplissage 30 % |
| Butée horizontale du bras supérieur |  | `01_Upper_Arm_Limit.step` | Bambu ABS Noir | 1 | buse 0,4, hauteur de couche 0,2, remplissage 30 % |
| Poignée du bras robotique |  | `01_Arm_Handle.step` | Bambu ABS Noir | 1 | buse 0,4, hauteur de couche 0,2, remplissage 30 % |
| Remplissage gauche de l’avant-bras |  | `01_Lower_Arm_Filler_L.step` | Bambu PLA Noir et Vert | 1 | buse 0,4, hauteur de couche 0,2, remplissage 15 % |
| Remplissage droit de l’avant-bras |  | `01_Lower_Arm_Filler_R.step` | Bambu PLA Noir et Vert | 1 | buse 0,4, hauteur de couche 0,2, remplissage 15 % |
| Remplissage central de l’avant-bras |  | `01_Lower_Arm_Filler_M.step` | Bambu ABS Noir | 1 | buse 0,4, hauteur de couche 0,2, remplissage 30 % |
| Cache décoratif du bras supérieur |  | `01_Upper_Arm_Cover.step` | Bambu PLA Vert | 1 | buse 0,4, hauteur de couche 0,2, remplissage 15 % |
| Cache décoratif de l’avant-bras |  | `01_Lower_Arm_Cover.step` | Bambu PLA Vert | 1 | buse 0,4, hauteur de couche 0,2, remplissage 15 % |
| Cache de protection du moteur n° 5 |  | `01_Motor_Cover.step` | Bambu ABS Noir | 1 | buse 0,4, hauteur de couche 0,2, remplissage 30 % |
| Butée horizontale de la pince |  | `01_Lower_Arm_Limit.step` | Bambu PLA Vert | 1 | buse 0,4, hauteur de couche 0,2, remplissage 15 % |
| Support de remplissage du coulisseau de pince |  | `01-Rail-Bracket.step` | Bambu PLA Vert | 1 | buse 0,4, hauteur de couche 0,2, remplissage 15 % |
| Pince |  | `01_Finger.step` | Bambu ABS Noir | 2 | buse 0,4, hauteur de couche 0,2, remplissage 45 % |
| | `Prix de référence` | Moyenne **50 $** | | | Le prix peut varier légèrement selon le prix des matériaux d’impression et le temps d’impression en usine |

### 🧩 Recommandations d’impression

* Hauteur de couche : 0,2 mm
* Buse : 0,4 mm
* Supports : ajouter selon les besoins
* Matériaux : les pièces devant résister à la chaleur et à certaines contraintes utilisent un matériau ABS avec un remplissage de 30 % à 80 %, et peuvent également être remplacées par du nylon / des matériaux renforcés en fibre de carbone ; les pièces d’apparence/décoratives utilisent du PLA avec un remplissage de 15 %.
* Matériaux recommandés pour les pièces porteuses :

---

## 🔩 Pièces métalliques usinées

> [!WARNING]
> Certaines pièces pouvant être remplacées par une impression 3D sont indiquées dans les remarques ci-dessous, ce qui peut encore réduire considérablement les coûts.

| Description de la pièce | Image | Nom du fichier | Matériau | Quantité | Procédé de fabrication | Remarques |
| --- | --- | --- | --- | --- | --- | --- |
| Position de montage du roulement du moteur 1 |  | `02_Base_Motor_Shim.step` | Alliage d’aluminium 5052 | 1 | CNC | Peut être remplacé par de l’ABS imprimé en 3D avec un remplissage augmenté pour réduire le coût |
| Arbre rotatif du moteur 1 |  | `02_Arm_Yaw_Limit.step` | Alliage d’aluminium 5052 | 1 | CNC | Ajoute une limite de mouvement sur l’angle de lacet |
| Entretoise avant pour les moteurs 2 à 5 |   | `02_Motor_Front_Spacer.step`  | Alliage d’aluminium 5052 | 4 | CNC | Peut être remplacée par de l’ABS imprimé en 3D, remplissage 30 %, pour réduire le coût |
| Entretoise arrière pour les moteurs 2 à 4 |  | `02_Motor_Back_Spacer.step` | Alliage d’aluminium 5052 | 3 | CNC | |
| Bride arrière pour les moteurs 2 à 4 |  | `02_FLANGE.step` | Alliage d’aluminium 5052 | 3 | CNC | |
| Base du moteur de poignet 5 |  | `02_Wrist_Bracket.step` | Alliage d’aluminium 5052 | 1 | CNC | |
| Connecteur de pince A |  | `02_Gripper_Connector_A.step` | Alliage d’aluminium 5052 | 1 | CNC | |
| Connecteur de pince B |  | `02_Gripper_Connector_B.step` | Alliage d’aluminium 5052 | 1 | CNC | |
| Support métallique de coulisseau de pince |  | `02_Slider_Bracket.step` | Alliage d’aluminium 5052 | 1 | CNC | Peut être remplacé par de l’ABS imprimé en 3D avec un remplissage augmenté pour réduire le coût, mais non recommandé pour une utilisation à long terme |
| Coulisseau et connecteur de pince |  | `02_Slider_Extension.step` | Alliage d’aluminium 5052 | 2 | CNC | |
| Connecteur gauche d’articulation entre bras supérieur et inférieur |   | `02_Lower_Upper_Link_L.step`  | Alliage d’aluminium 5052 | 1 | CNC | |
| Connecteur droit d’articulation entre bras supérieur et inférieur  |   | `02_Lower_Upper_Link_R.step`  | Alliage d’aluminium 5052 | 1 | CNC | |
| Connecteur gauche d’articulation entre avant-bras et poignet |   | `02_Lower_Wrist_Link_L.step`  | Alliage d’aluminium 5052 | 1 | CNC | |
| Connecteur droit d’articulation entre avant-bras et poignet |   | `02_Lower_Wrist_Link_R.step`  | Alliage d’aluminium 5052 | 1 | CNC | |
| Connecteur d’engrenage |  | `02_Gear_Connector.step` | Alliage d’aluminium 5052 | 1 | CNC | Pour une faible charge, de l’ABS imprimé en 3D avec 80 % de remplissage peut être utilisé pour réduire le coût ; pour une charge élevée, l’usinage CNC métal est recommandé |
| Crémaillère |  | `02_Rack.step` | Alliage d’aluminium 5052 | 2 | CNC | |
| Lien 1 |  | `03-Link1.step` | Alliage d’aluminium 5052 | 1 | CNC + Tôlerie | |
| Lien 2 |  | `03-Link2.step` | Alliage d’aluminium 5052 | 2 | CNC + Tôlerie | |
| Lien 3 gauche |  | `03-Link3_L.step` | Alliage d’aluminium 5052 | 1 | CNC + Tôlerie | |
| Lien 3 droit |  | `03-Link3_R.step` | Alliage d’aluminium 5052 | 1 | CNC + Tôlerie | |
| Lien 5 |  | `03-Link5.step` | Alliage d’aluminium 5052 | 1 | CNC + Tôlerie | |
| Prix de référence multi-marché | | Moyenne **250 $** | | | | Le prix peut varier légèrement en raison des fluctuations du coût de l’aluminium 5052, des exigences de précision d’usinage, des délais d’usine, etc. |

### 🧩 Instructions d’usinage

* Tolérance dimensionnelle critique : ±0,02 mm, GB/T1840-M ;
* Traitement de surface : anodisation / sablage
* Il est recommandé d’utiliser H7 / ajustement serré pour les pièces en contact

---

## 🛒 Pièces achetées (pièces standard)

> [!WARNING]
> Étant donné que tout le monde devra assembler et serrer les vis soi-même, des vis hexagonales intérieures standard ont été choisies. Après un fonctionnement prolongé, les vis risquent de se desserrer, ce qui affectera la précision du bras robotique.
Vous devez donc acheter en plus de la colle thermofusible pour effectuer un traitement anti-desserrement sur les vis de chaque articulation. Si vous disposez d’une perceuse électrique ou d’outils similaires, vous pouvez acheter des vis autobloquantes. Cependant, il est extrêmement important d’utiliser le réglage de force le plus faible avec un tournevis électrique, afin d’éviter d’arracher les filets et de causer des dommages irréversibles.

| Nom | Spécification / Modèle | Quantité  | Prix de référence | Remarques |
| --- | --- | --- | --- | --- |
| Moteur sans balais | DM4310(V4) | 4 | 120 $/unité | [SeeedStudio](https://www.seeedstudio.com/DIP-Servo-Motor-24V-120RPM-Brushless-98-9mm-4P-L56-W56-H46mm-p-6660.html) |
| Moteur sans balais | DM4340P(V4) | 3 | 175 $/unité | [SeeedStudio](https://www.seeedstudio.com/DM4340P-Actuator-p-6663.html) |
| Carte pilote CAN-USB | | 1 | 15 $/unité | [SeeedStudio](https://www.seeedstudio.com/DM-CAN-USB-Driver-Borad-p-6706.html) |
| Roulement | 6707ZZ | 1 | 13 $/unité | [Amazong](https://www.amazon.com/uxcell-35x44x5mm-Shielded-Precision-Lubricated/dp/B0D6WBMW3F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) |
| Roulement | 6803ZZ | 3 | 13 $/unité | [Amazong](https://www.amazon.com/uxcell-17x26x5mm-Shielded-Precision-Lubricated/dp/B0D54JSWBZ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) |
| Roulement | AXK5578 | 1 | 12 $/unité | [Amazong](https://www.amazon.com/PZRT-AXK5578-Thrust-Bearings-Washers/dp/B0B3M3RZGW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) |
| Rail linéaire | MGN9-170mm | 1 | 23 $/unité | [Amazong](https://www.amazon.com/uxcell-Sliding-Carriage-Bearing-Printers/dp/B0D54L45WM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) |
| Bloc coulissant | MGN9 | 2 | 10 $/unité | [Amazong](https://www.amazon.com/uxcell-Bearing-Sliding-Carriage-Anti-Fall/dp/B0D9QBQDKB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) |
| Engrenage | Module 1, type moyeu, 16 dents, alésage 6 mm | 1 | 44$/unité | [Amazong](https://www.amazon.com/Module-15-Teeth-Finished-Perforation/dp/B0GDSR1LKM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) |
| Tampon en silicone | 30*9*2mm | 1 | 10 $ | [Amazong](https://www.amazon.com/Self-Adhesive-Anti-Sliding-Anti-Scratch-Protectors-Appliances/dp/B0F9KVYXFZ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) |
| Entretoise en cuivre | M4x50mm | 4 | 8 $ | [Amazong](https://www.amazon.com/Female-Standoff-Quadcopter-Computer-Circuit/dp/B09V2CYDMG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) |
| Vis | Vis M3*22mm | Plusieurs | | [Amazong](https://www.amazon.com/METERXITY-50-Pack-Stainless-Threaded-Fasteners/dp/B0FLYG7WZ7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) |
| Vis | Vis M4*16mm | Plusieurs | | [Amazong](amazon.com/BNUOK-120pcs-Stainless-Threads-Spanner/dp/B0DYNFFB7Q/ref=sr_1_9?crid=W94HLTGLCH57&dib=eyJ2IjoiMSJ9.jg07IMpJdHhW8vR9Ewx53UNnQs_QkpENya6ZqIQWoB6rsXjPLmfWMgAytRy7neNPJJHQzVyP9H7FO5sm9KN9I34nKUQsLRZAG48Rs2rSHwlh2mpA2IPlezHLRlvLN49IIbiHgk5Y63iPwAaxKT27sG3dhyXpf-EABXWIlgUu0FBQ3IIA5kiQDccrsIPN06nR6XBFnNeTu1ogpvhiaZsK7R-VRXcFAsrQvOc4tnzXLlTSM68gR8hBmGYZtQUoOJrRo93U1xfGf7kODnnOqUBWI3VhQIMgnl8Rtt4pl3H7IK0._jHfn0N3UQ0z_FJlv4C8jBXiadkqdO-IHWJzQ3xlm0w&dib_tag=se&keywords=M4*16mm+screw&qid=1774772422&s=industrial&sprefix=m4+16mm+screw%2Cindustrial%2C364&sr=1-9) |
| Vis | Vis sans tête M3*8mm | 5 | 5$ | [Amazong](https://www.amazon.com/Headless-Internal-Stainless-Concave-External/dp/B0D8TGXG9D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) |
| Vis | Vis fraisée M3*22mm | Plusieurs | | [Amazong](https://www.amazon.com/Countersunk-DIN7991-Stainless-Threaded-Fasteners/dp/B0CG1PV6SH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) |
| Vis | Vis fraisée M3*8mm | Plusieurs | | [Amazong](https://www.amazon.com/Countersunk-DIN7991-Stainless-Threaded-Fasteners/dp/B0CG1PV6SH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) |
| Vis | Vis fraisée M3*16mm | Plusieurs | | [Amazong](https://www.amazon.com/Countersunk-DIN7991-Stainless-Threaded-Fasteners/dp/B0CG1PV6SH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) |
| Vis | Vis autotaraudeuse M3*12mm | Plusieurs | | [Amazong](https://www.amazon.com/Countersunk-DIN7991-Stainless-Threaded-Fasteners/dp/B0CG1PV6SH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) |
| Goupille | M4*8mm | Plusieurs | | [Amazong](https://www.amazon.com/Countersunk-DIN7991-Stainless-Threaded-Fasteners/dp/B0CG1PV6SH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) |
| Goupille | M4*12mm | Plusieurs | | [Amazong](https://www.amazon.com/Countersunk-DIN7991-Stainless-Threaded-Fasteners/dp/B0CG1PV6SH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) |
| Jeu de tournevis | Jeu de clés hexagonales | 1 | 16$ | [Amazong](amazon.com/Amazon-Basics-Ratcheting-Electronics-Screwdriver/dp/B07V4TFWFZ/ref=sr_1_2?crid=ADAY70RZDSLN&dib=eyJ2IjoiMSJ9.jcLL4o6IXTnPlPfTTzbCZCBuZx2sLkvdUQCwlL58aq__GOyLxVPnwLI0mvGptba_HeVz6ctLQ_ziQw56BMDH9IOaw-4PVJGMktQM74mWficwggm3ckDGyAH-agN_zkB3K0_W-wrS56jfcMYFbZSWhWxr-iSOC4sdXwMGlt4rYGtenyn9yAFYBIHqjU2El5_OAKuspsrF0yQvfyfQPQHs46SClWN8zlSemGVZRuVSU26f0f9yApF6BfWHANKNNhT0Mfb6bQ8oM2XUMvwaazrrKoHeTARuoflVaVZvMU776bs.r8gy_gMINEy0qy4JyK--z-IbPZEv-SWeMGohOOE7M60&dib_tag=se&keywords=Screwdriver+set&qid=1774772499&s=industrial&sprefix=screwdriver+set+%2Cindustrial%2C374&sr=1-2) |
| Personnalisation requise  | XT30 2+2 350mm | 2 | 4 $/câble | Les deux extrémités sont coudées |
| Personnalisation requise  | XT30 2+2 350mm | 1 | 4 $/câble | Une extrémité coudée et une extrémité droite |
| Personnalisation requise  | XT30 2+2 200mm | 3 | 4 $/câble | Les deux extrémités sont coudées |
| Personnalisation requise  | XT30 2+2 200mm | 1 | 3 $/câble | Les deux extrémités sont droites |
| Serre-joint de menuiserie | Serre-joint en G 6 pouces | 2 | 20 $/unité | [Amazong](https://www.amazon.com/gp/aw/d/B092J1YW2M/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) |
| Alimentation | 24V 14.6A | 1 | 30$ | [Amazong](https://www.amazon.com/MEAN-WELL-LRS-350-24-350-4W-Switchable/dp/B013ETVO12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) |
| Câble d’alimentation | 12AWG | 1 | 30 $ | [Amazong](https://www.amazon.com/Pinfox-Universal-Appliance-Replacement-Pigtail/dp/B0F5PW5SJG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) |
| Câble d’alimentation | XT30 16awg | 1 | 9 $ | [Amazong](https://www.amazon.com/RioRand-Connector-Pigtail-Silicone-Aircraft/dp/B0FY2ZCR83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) |

---

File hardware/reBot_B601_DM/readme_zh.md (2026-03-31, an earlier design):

# 🤖 reBot DevArm 开源硬件说明

<p align="center">
  reBot-DevArm Banner
</p>
<p align="center">
  <strong>
    <a href="./readme_zh.md">简体中文</a> &nbsp;|&nbsp;
    <a href="./readme.md">English</a> &nbsp;|&nbsp;
    <a href="./readme_jp.md">日本語</a>&nbsp;|&nbsp;
    <a href="./readme_fr.md">français</a>&nbsp;|&nbsp;
    <a href="./readme_es.md">Español</a>
  </strong>
</p>

当前BOM为reBot Arm B601 DM机械臂清单，所使用的是Damiao43系列电机，另一款reBot Arm B601 RS机械臂所使用的是RobStride电机，[清单请看这里](../reBot_B601_RS/README.md)

# 📦 文件结构
*   `3D_Printed_Parts/`: 所有3D打印文件的Step。
*   `Metal_Parts/`: 所有金属加工文件的Step。
*   `Purchased_Parts/`: 所有购买件的Step。
*   `reBot_B601_DM_v1.0_20260331.step`: 机械臂整体装配文件。

# 📊 物料清单（BOM）

> [!WARNING]
>特此申明，公布的BOM并非代表Seeed出货的最终版本，此`v1.0`开源版本是方便开发者并能够尽可能减少成本自己加工复现的版本,减少了一些不必要的细节开支，Seeed 最终出货版本会有金属镭雕防呆提示，部分3D打印件为了耐久会替换为金属件，根据金属加工厂的误差做间隙和加工精度调整（精度和成本的平衡），线束的特殊定制（例如增加编制绳保护）等需要增加一定成本的细节优化，但是结构构型相同。

---

## 🖨️ 3D打印件

|  零件描述 | 图片 | 文件名 | 材料 | 数量 | 备注 |
|---|---|---|---|---|---|
| 机械臂底座平台 |  | `01_BASE_Plate.step` | 拓竹 ABS 黑色  |  1 |  0.4喷嘴 0.2层高 30%填充 |
| 机械臂底座 |  | `01_BASE_Link.step` | 拓竹 ABS 黑色  |  1 |  0.4喷嘴 0.2层高 30%填充 |
| 大臂左侧填充 |  | `01_Upper_Arm_Fuller_L.step` | 拓竹 PLA 黑色和绿色  |  1 |  0.4喷嘴 0.2层高 15%填充 |
| 大臂右侧填充 |  | `01_Upper_Arm_Fuller_R.step` | 拓竹 PLA 黑色和绿色 |  1 |  0.4喷嘴 0.2层高 15%填充 |
| 大臂中间填充 |  | `01_Upper_Arm_Fuller_M.step` | 拓竹 ABS 黑色  |  1 |  0.4喷嘴 0.2层高 30%填充 |
| 大臂水平限位块 |  | `01_Upper_Arm_Limit.step` |拓竹 ABS 黑色  |  1 |  0.4喷嘴 0.2层高 30%填充 |
| 机械臂提手 |  | `01_Arm_Handle.step` |拓竹 ABS 黑色  |  1 |  0.4喷嘴 0.2层高 30%填充 |
| 小臂左侧填充 |  | `01_Lower_Arm_Filler_L.step` |拓竹 PLA 黑色和绿色  |  1 |  0.4喷嘴 0.2层高 15%填充 |
| 小臂右侧填充 |  | `01_Lower_Arm_Filler_R.step` |拓竹 PLA 黑色和绿色  |  1 |  0.4喷嘴 0.2层高 15%填充 |
| 小臂中间填充 |  | `01_Lower_Arm_Filler_M.step` |拓竹 ABS 黑色  |  1 |  0.4喷嘴 0.2层高 30%填充 |
| 大臂装饰 |  | `01_Upper_Arm_Cover.step` |拓竹 PLA 绿色  |  1 |  0.4喷嘴 0.2层高 15%填充 |
| 小臂装饰 |  | `01_Lower_Arm_Cover.step` |拓竹 PLA 绿色  |  1 |  0.4喷嘴 0.2层高 15%填充 |
| 5号电机保护盖 |  | `01_Motor_Cover.step` |拓竹 ABS 黑色  |  1 |  0.4喷嘴 0.2层高 30%填充 |
| 夹爪水平限位 |  | `01_Lower_Arm_Limit.step` |  拓竹 PLA 绿色  |  1 |  0.4喷嘴 0.2层高 15%填充 |
| 夹爪滑块填充支架 |  | `01-Rail-Bracket.step` |  拓竹 PLA 绿色  |  1 |  0.4喷嘴 0.2层高 15%填充 |
| 夹爪  |  | `01_Finger.step` |  拓竹 ABS 黑色  |  2 |  0.4喷嘴 0.2层高 45%填充 |
| | `参考价格` | 平均**350RMB**  | |  | 因打印材料价格、和工厂打印时长不同，价格略有浮动|  |  

### 🧩 打印建议
- 层高：0.2 mm
- 喷嘴：0.4 mm
- 支撑：按需添加  
- 材料：需要受到高温和一定力的部分使用的是ABS材料并且填充在30%~80%，也可以改为尼龙 / 碳纤增强材料，外观装饰件使用的是PLA，填充15%。
- 受力件建议材料：

---

## 🔩 金属加工件

> [!WARNING]
> 这里部分可用3D打印替代的零件已在备注中表明，可极大进一步降低成本开支。

| 零件描述 | 图片 | 文件名 | 材料 | 数量 |  加工工艺 |  备注 |
|---|---|---|---|---|---|---|
| 电机1轴承安装位 |  | `02_Base_Motor_Shim.step` |铝合金5052  | 1 | CNC| 可用3D打印ABS，增加填充来降低成本  | 
| 电机1旋转轴 |  | `02_Arm_Yaw_Limit.step` |铝合金5052  | 1 | CNC| 增加了航向角的运动限位 | 
| 电机2-5的正面垫片 |  | `02_Motor_Front_Spacer.step` |铝合金5052  | 4 | CNC| 可用3D打印ABS，30%填充来降低成本 | 
| 电机2-4的背面垫片 |  | `02_Motor_Back_Spacer.step` |铝合金5052  | 3 | CNC|  | 
| 电机2-4的背面法兰 |  | `02_FLANGE.step` |铝合金5052  | 3 | CNC| | 
| 腕部电机5底座 |  | `02_Wrist_Bracket.step` |铝合金5052  | 1 | CNC|  | 
| 爪子连接器A |  | `02_Gripper_Connector_A.step` |铝合金5052  | 1 | CNC|  | 
| 爪子连接器B |  | `02_Gripper_Connector_B.step` |铝合金5052  | 1 | CNC|  | 
| 爪子滑块金属支架 |  | `02_Slider_Bracket.step` |铝合金5052  | 1 | CNC|  可用3D打印ABS，增加填充来降低成本，但是不推荐长期使用 | 
| 滑块与爪子连接器 |  | `02_Slider_Extension.step` |铝合金5052  | 2 | CNC| | 
| 大小臂关节连接件左 |  | `02_Lower_Upper_Link_L.step` |铝合金5052  | 1 | CNC|  | 
| 大小臂关节连接件右 |  | `02_Lower_Upper_Link_R.step` |铝合金5052  | 1 | CNC|  | 
| 小臂与腕关节连接件左 |  | `02_Lower_Wrist_Link_L.step` |铝合金5052  | 1 | CNC|  | 
| 小臂与腕关节连接件右 |  | `02_Lower_Wrist_Link_R.step` |铝合金5052  | 1 | CNC| | 
| 齿轮连接器  |  | `02_Gear_Connector.step` |  铝合金5052  |  1 |  CNC | 低负载可用3D打印ABS，填充80%使用来降低成本，高负载推荐使用CNC金属加工 |
| 齿条  |  | `02_Rack.step` |  铝合金5052  |  2 |  CNC |  |
| 连杆1  |  | `03-Link1.step` |  铝合金5052  |  1 |  CNC+钣金 | |
| 连杆2  |  | `03-Link2.step` |  铝合金5052  |  2 |  CNC+钣金 |  |
| 连杆3左  |  | `03-Link3_L.step` |  铝合金5052  |  1 |  CNC+钣金 |  |
| 连杆3右  |  | `03-Link3_R.step` |  铝合金5052  |  1 |  CNC+钣金 |  |
| 连杆5  |  | `03-Link5.step` |  铝合金5052  |  1 |  CNC+钣金 |  |
| 多家市场参考价格  |  | 平均**1500RMB**  | |  | 因铝5052成本浮动、加工精度要求、工厂交期等，价格略有浮动|  |  

### 🧩 加工说明
- 关键尺寸公差：±0.02 mm GB/T1840-M；
- 表面处理：阳极氧化 / 喷砂   
- 配合件建议采用 H7 / 过盈配合  

---

## 🛒 外购件（标准件）

> [!WARNING]
> 考虑到大家需要自己组装拧螺丝，所以选购的螺丝是普通的内六角螺丝，长时间运行后可能会出现螺丝松动从而影响机械臂精度，这里需要大家额外购买热熔胶去对每个关节处的螺丝进行防松操作，如果大家手上有电钻等，可以购买防松螺丝，但是切记使用电动螺丝刀要用最小档的力，防止螺丝滑丝造成无法逆转的损失（非常重要）。

| 名称 | 规格型号 | 数量 | 参考价格 | 备注 |
|---|---|---|---|---|
| 无刷电机 | DM4310(V4) | 4 | 599 元/颗 | [淘宝](https://item.taobao.com/item.htm?id=815333472865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) |
| 无刷电机 | DM4340P(V4) | 3 | 899 元/颗 | [淘宝](https://item.taobao.com/item.htm?id=849494670743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) |
| CAN-USB驱动板 |  | 1 | 60 元/颗 | [淘宝](https://item.taobao.com/item.htm?id=815478282425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) |
| CAN-电源分离板 |  | 1 | 9 元/颗 | [淘宝](https://item.taobao.com/item.htm?id=815810342495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) |
| 轴承 | 6707ZZ | 1 | 14.8元/个 | [淘宝](https://item.taobao.com/item.htm?id=14242929760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) |
| 轴承 | 6803ZZ | 3 | 1.25元/个 | [淘宝](https://item.taobao.com/item.htm?id=14777231362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) |
| 轴承 | AXK5578 | 1 | 17元/个 | [淘宝](https://item.taobao.com/item.htm?id=775311326057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) |
| 滑轨 | MGN9-170mm | 1 | 20元/个 | [淘宝](https://item.taobao.com/item.htm?id=709992228016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) |
| 滑块 | MGN9 | 2 | 20元/个 | [淘宝](https://item.taobao.com/item.htm?id=709992228016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) |
| 齿轮 | 1模凸台16齿内孔5 | 1个 | 4.9元 | [淘宝](https://item.taobao.com/item.htm?id=725141098339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)  |
| 硅胶垫 | 30*9*2mm | 1个 | 4.6元 | [淘宝](https://item.taobao.com/item.htm?id=952654692170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)  |
| 铜柱 | M4x50mm | 4个 | 10元 | [淘宝](https://detail.tmall.com/item.htm?id=542213588710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)  |
| 螺丝 | M3*22mm螺丝| 若干 |  | [淘宝](https://detail.tmall.com/item.htm?id=635755541429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) |
| 螺丝 | M4*16mm螺丝| 若干 |  | [淘宝](https://detail.tmall.com/item.htm?id=635755541429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) |
| 螺丝 | M3*8mm无头螺丝| 5 |  | [淘宝](https://detail.tmall.com/item.htm?id=16948094393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) |
| 螺丝 | M3*22mm埋头螺丝| 若干 |  | [淘宝](https://detail.tmall.com/item.htm?id=587689015567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) |
| 螺丝 | M3*8mm埋头螺丝| 若干 |  | [淘宝](https://detail.tmall.com/item.htm?id=587689015567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) |
| 螺丝 | M3*16mm埋头螺丝| 若干 |  | [淘宝](https://detail.tmall.com/item.htm?id=587689015567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) |
| 螺丝 | M3*12mm自攻螺丝| 若干 |  | [淘宝](https://item.taobao.com/item.htm?id=37344431027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) |
| 定位销 | M4*8mm| 若干 |  | [淘宝](https://detail.tmall.com/item.htm?id=713343372783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) |
| 定位销 | M4*12mm| 若干 |  | [淘宝](https://detail.tmall.com/item.htm?id=713343372783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) |
| 螺丝刀套装 | 内六角 | 1 |  | [淘宝](https://item.taobao.com/item.htm?id=562945549227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) |
| 需定制 | XT30 2+2 350mm  | 2 | 25元/根 | [两端弯头](https://item.taobao.com/item.htm?id=45608377884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) |
| 需定制 | XT30 2+2 350mm  | 1 | 25元/根| [一侧弯头一侧直头](https://item.taobao.com/item.htm?id=45608377884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) |
| 需定制 | XT30 2+2 200mm  | 3 | 22元/根 | [两端弯头](https://item.taobao.com/item.htm?id=45608377884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) |
| 需定制 | XT30 2+2 200mm  | 1 | 15元/根 | [两端直头](https://item.taobao.com/item.htm?id=45608377884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) |
| 木工夹 | 6寸G夹 | 2 | 23.8元/个 | [淘宝](https://detail.tmall.com/item.htm?id=586725303306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) |
| 电源 | 24V 14.6A | 1 | 105元 | [淘宝](https://item.taobao.com/item.htm?id=768444771109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) |
| 电源 | 3插头 | 1 | 10元 | [淘宝](https://item.taobao.com/item.htm?id=960503559387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) |
| 电源 | XT30 16号线 | 1 | 32元 | [淘宝](https://item.taobao.com/item.htm?id=911228476782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) |

---

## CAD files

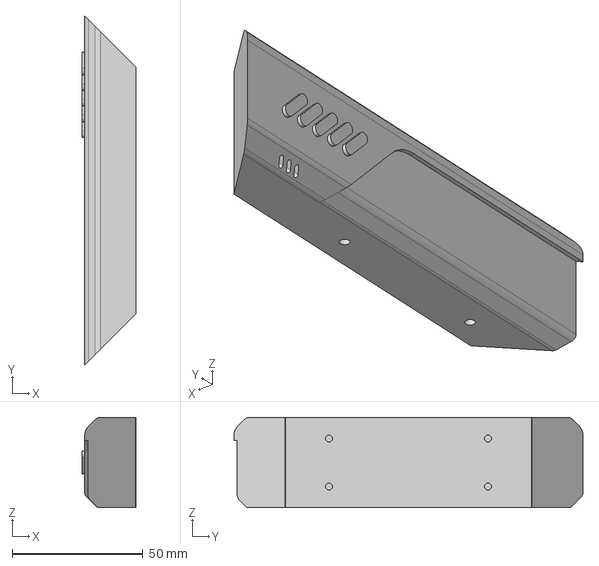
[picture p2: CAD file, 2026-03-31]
hardware/reBot_B601_DM/3D_Printed_Parts/01_Upper_Arm_Fuller_L.step
20.6 x 133.6 x 34.6 mm

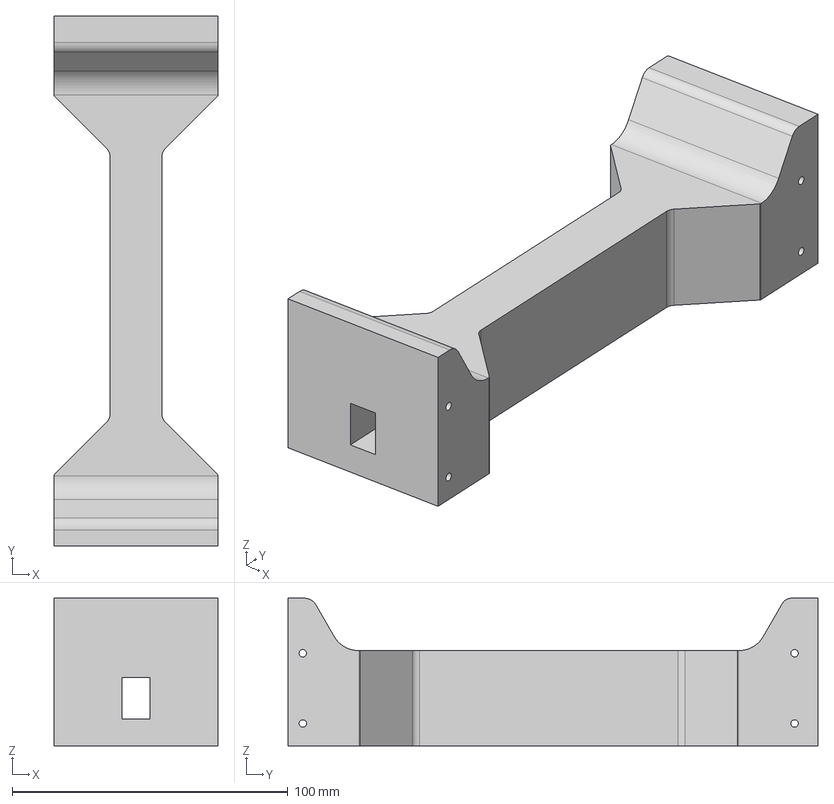
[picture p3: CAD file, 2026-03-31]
hardware/reBot_B601_DM/3D_Printed_Parts/01_Upper_Arm_Fuller_M.step
59.4 x 192.4 x 53.6 mm

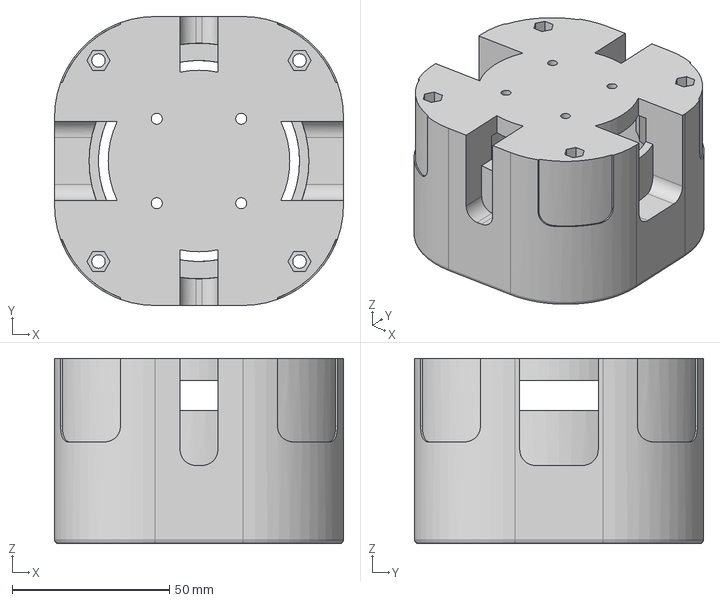
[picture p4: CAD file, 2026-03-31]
hardware/reBot_B601_DM/3D_Printed_Parts/01_BASE_Link.step
92.0 x 92.0 x 59.0 mm

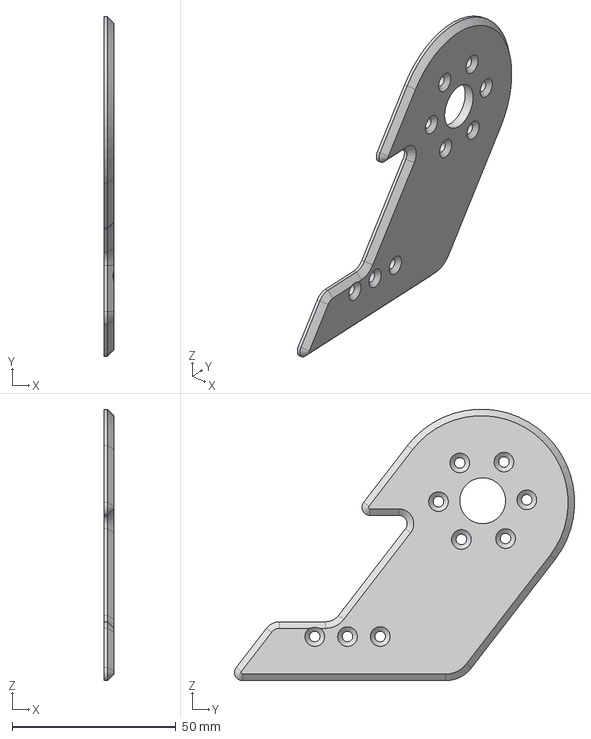
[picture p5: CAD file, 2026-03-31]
hardware/reBot_B601_DM/Metal_Parts/02_Lower_Wrist_Link_R.step
3.00 x 103.9 x 82.9 mm

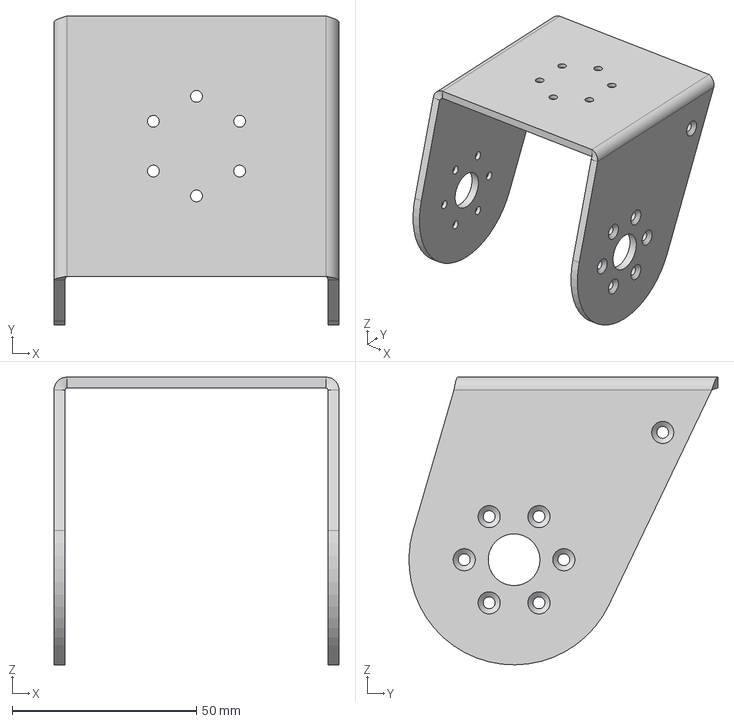
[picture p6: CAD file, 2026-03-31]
hardware/reBot_B601_DM/Metal_Parts/03-Link1.step
77.2 x 83.8 x 78.0 mm

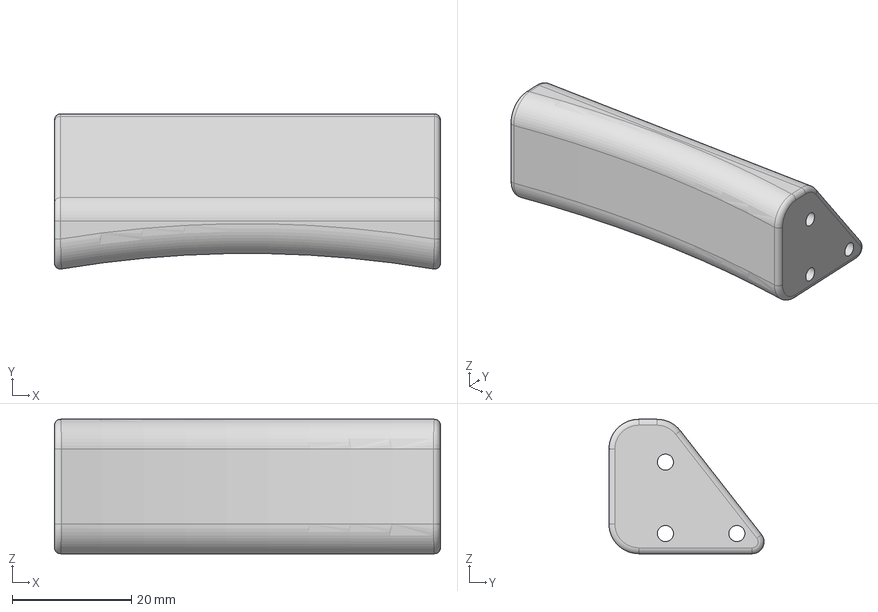
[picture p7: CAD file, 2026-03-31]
hardware/reBot_B601_DM/3D_Printed_Parts/01_Arm_Handle.step
64.8 x 26.1 x 22.6 mm

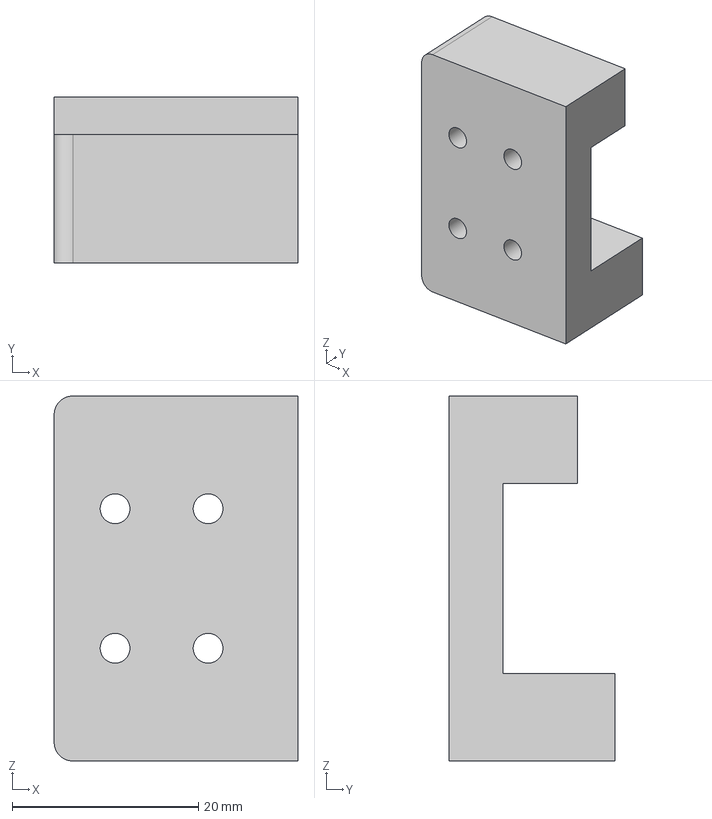
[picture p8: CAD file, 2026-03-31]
hardware/reBot_B601_DM/Metal_Parts/02_Slider_Extension.step
26.2 x 17.8 x 39.2 mm

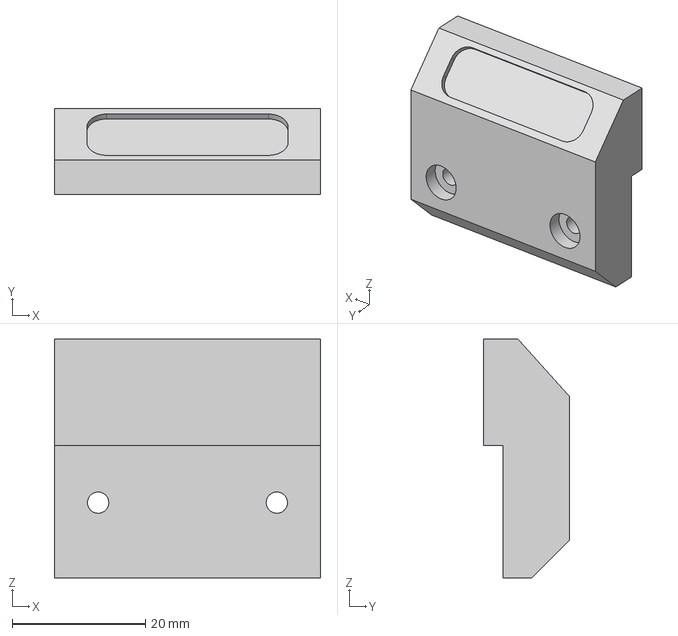
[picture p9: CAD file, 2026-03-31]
hardware/reBot_B601_DM/3D_Printed_Parts/01_Lower_Arm_Limit.step
40.0 x 13.0 x 35.9 mm

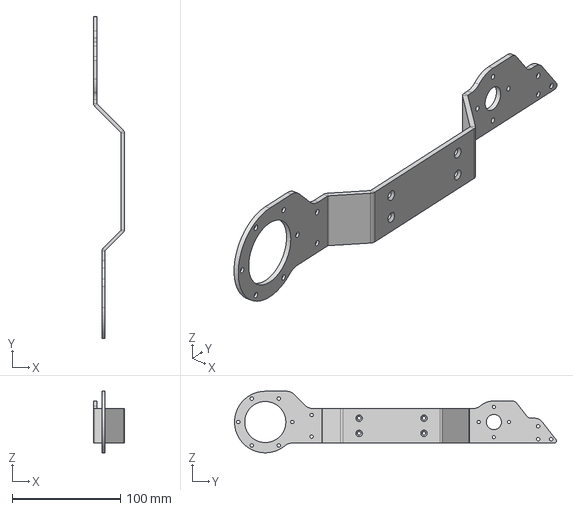
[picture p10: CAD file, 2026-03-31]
hardware/reBot_B601_DM/Metal_Parts/03-Link3_L.step
28.6 x 297.8 x 57.0 mm

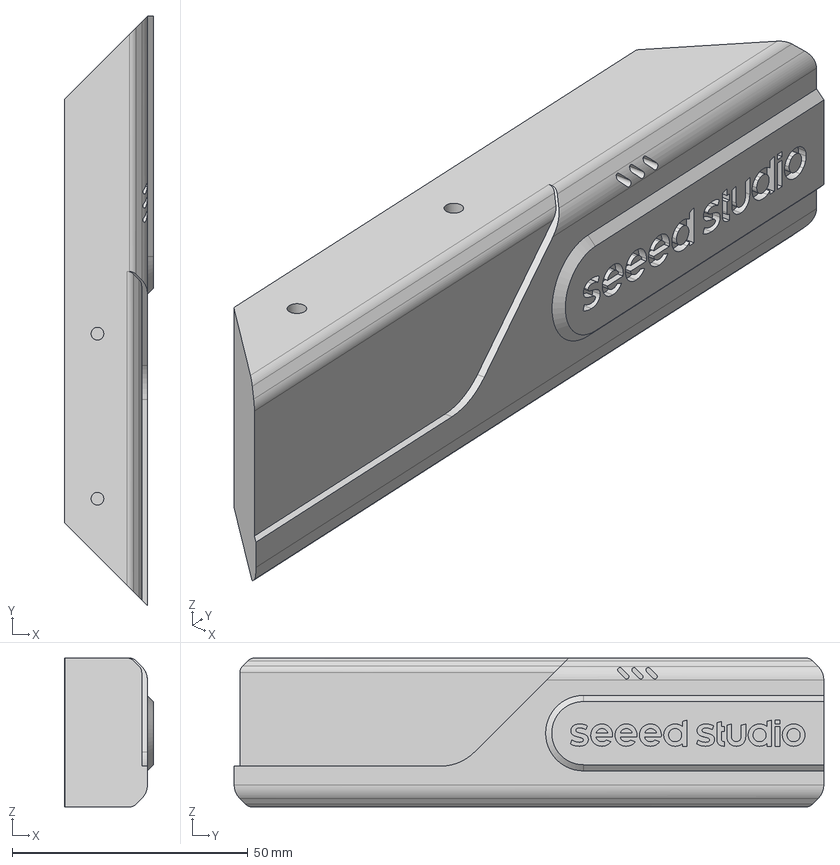
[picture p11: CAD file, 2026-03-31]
hardware/reBot_B601_DM/3D_Printed_Parts/01_Lower_Arm_Filler_R.step
18.9 x 125.0 x 31.6 mm

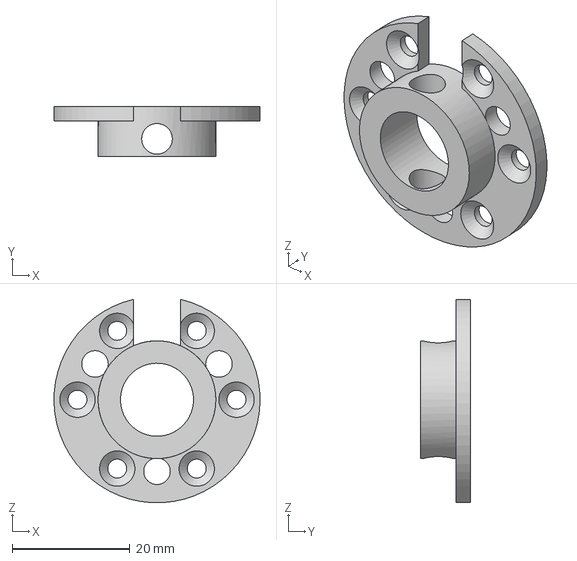
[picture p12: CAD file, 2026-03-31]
hardware/reBot_B601_DM/Metal_Parts/02_Gear_Connector.step
35.0 x 8.50 x 34.5 mm

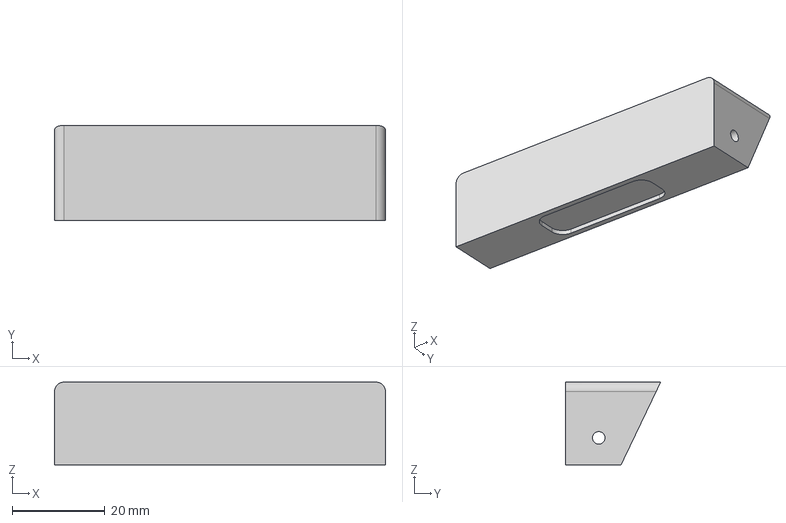
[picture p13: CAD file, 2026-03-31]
hardware/reBot_B601_DM/3D_Printed_Parts/01_Upper_Arm_Limit.step
71.2 x 20.5 x 17.8 mm

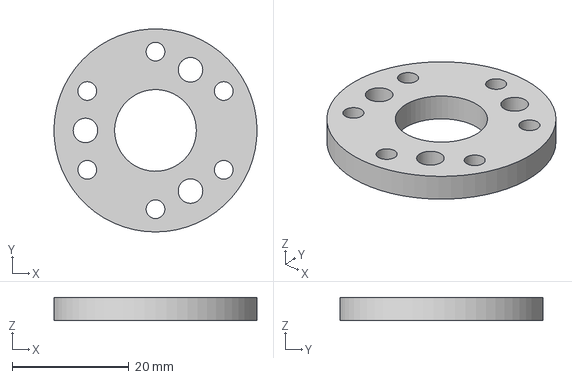
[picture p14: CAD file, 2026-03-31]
hardware/reBot_B601_DM/Metal_Parts/02_Motor_Front_Spacer.step
34.8 x 34.8 x 4.00 mm

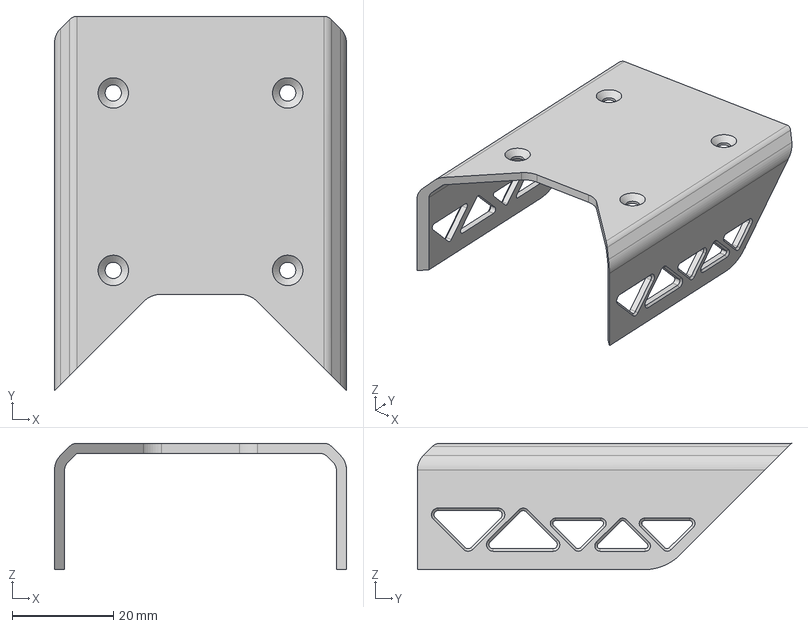
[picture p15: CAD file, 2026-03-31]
hardware/reBot_B601_DM/3D_Printed_Parts/01_Lower_Arm_Cover.step
57.6 x 73.8 x 24.9 mm

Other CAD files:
hardware/reBot_B601_DM/3D_Printed_Parts/01_Upper_Arm_Fuller_R.step
hardware/reBot_B601_DM/Metal_Parts/02_Base_Motor_Shim.step
hardware/reBot_B601_DM/3D_Printed_Parts/01_Upper_Arm_Cover.step
hardware/reBot_B601_DM/Metal_Parts/02_Motor_Back_Spacer.step
hardware/reBot_B601_DM/3D_Printed_Parts/01-Rail-Bracket.step
hardware/reBot_B601_DM/3D_Printed_Parts/01_BASE_Plate.step
hardware/reBot_B601_DM/3D_Printed_Parts/01_Finger.step
hardware/reBot_B601_DM/3D_Printed_Parts/01_Lower_Arm_Filler_L.step
hardware/reBot_B601_DM/3D_Printed_Parts/01_Lower_Arm_Filler_M.step
hardware/reBot_B601_DM/3D_Printed_Parts/01_Motor_Cover.step
hardware/reBot_B601_DM/Metal_Parts/02-RACK.step
hardware/reBot_B601_DM/Metal_Parts/02_Arm_Yaw_Limit.step
hardware/reBot_B601_DM/Metal_Parts/02_FLANGE.step
hardware/reBot_B601_DM/Metal_Parts/02_Lower_Upper_Link_L.step
hardware/reBot_B601_DM/Metal_Parts/02_Lower_Upper_Link_R.step
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

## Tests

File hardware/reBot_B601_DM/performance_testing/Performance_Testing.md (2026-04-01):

# 🧪 reBot-DevArm Physical Performance Testing Reference

<p align="center">
  reBot-DevArm Banner
</p>

<p align="center">
  <strong>
    <a href="./Performance_Testing_zh.md">简体中文</a> &nbsp;|&nbsp;
    <a href="./Performance_Testing.md">English</a> &nbsp;|&nbsp;
    <a href="./Performance_Testing_JP.md">日本語</a>&nbsp;|&nbsp;
    <a href="./Performance_Testing_Fr.md">français</a>&nbsp;|&nbsp;
    <a href="./Performance_Testing_es.md">Español</a>
  </strong>
</p>

> [!NOTE]
> This document provides performance testing data reference for the reBot Arm B601-DM under normal and extreme working conditions.

> [!WARNING]
> **Version Difference Notice**: This test is based on the reBot Arm B601-DM equipped with **Damiao V4 version motors**. **V3 and earlier motor versions have performance differences**. Test data is for reference only; actual performance should be verified through testing.

---

## 💡 Quick Summary

**Test Termination Reason**: All tests were terminated due to **Motor 2 (upper arm joint) overheat protection**, not mechanical structural failure.

**Dynamic Motion Test** (Single motion cycle: 5s standard, reciprocating motion):

| Reach Range | Load | Duration | Termination Reason |
|---|---|---|---|
| 5%~70% Rated Reach | 1.5 kg | > 2 h | Motor 2 temperature reached 90℃ |
| 5%~70% Rated Reach | 2.5 kg | 40 min | Motor 2 overheat protection |
| 5%~100% Rated Reach | 1.5 kg | 45 min | Motor 2 overheat protection |

**Static Holding Test**:

| Reach Position | Load | Duration | Termination Reason |
|---|---|---|---|
| 70% Rated Reach | 1.5 kg | 18 min | Motor 2 overheat protection |
| 100% Rated Reach | 1.5 kg | 3 min | Motor 2 overheat protection |

> 👉 **Key Conclusion**: The manipulator structural strength is sufficient. Test termination was due to **Motor 2 overheat protection**. Recommended working load is **1.5 kg or less**, working reach is recommended to be **less than 70%**, and adding active cooling measures is advised.

---

## 📋 Table of Contents

- [⚡ Extreme Working Performance Test](#-extreme-working-performance-test)
- [📈 Official Load Curve](#-official-load-curve)
- [📝 Test Conclusions and Recommendations](#-test-conclusions-and-recommendations)
- [🙋 Frequently Asked Questions (FAQ)](#-frequently-asked-questions-faq)
- [📅 Update History](#-update-history)
- [📞 Technical Support](#-technical-support)

---

## ⚡ Extreme Working Performance Test

### Test Conditions

**Dynamic Motion Test**:
- Single motion cycle duration: 5 s
- Motion mode: Reciprocating motion
- Test reach range: 5%~70% / 5%~100% rated reach

**Static Holding Test**:
- Test posture: Static posture with load holding
- Test reach: 70% / 100% rated reach

### Test Results

#### 1. Dynamic Motion Test

| Test Position | Load (kg) | Max Duration | Termination Reason |
|---|---|---|---|
| Reach 5%~70% | 1.5 | > 2 h | Motor 2 overheat protection |
| Reach 5%~70% | 2.5 | 40 min | Motor 2 overheat protection |
| Reach 5%~100% | 1.5 | 45 min | Motor 2 overheat protection |

#### 2. Static Holding Test

| Test Position | Load (kg) | Max Duration | Termination Reason |
|---|---|---|---|
| Reach 70% | 1.5 | 18 min | Motor 2 overheat protection |
| Reach 100% | 1.5 | 3 min | Motor 2 overheat protection |

---

## 📈 Official Load Curve

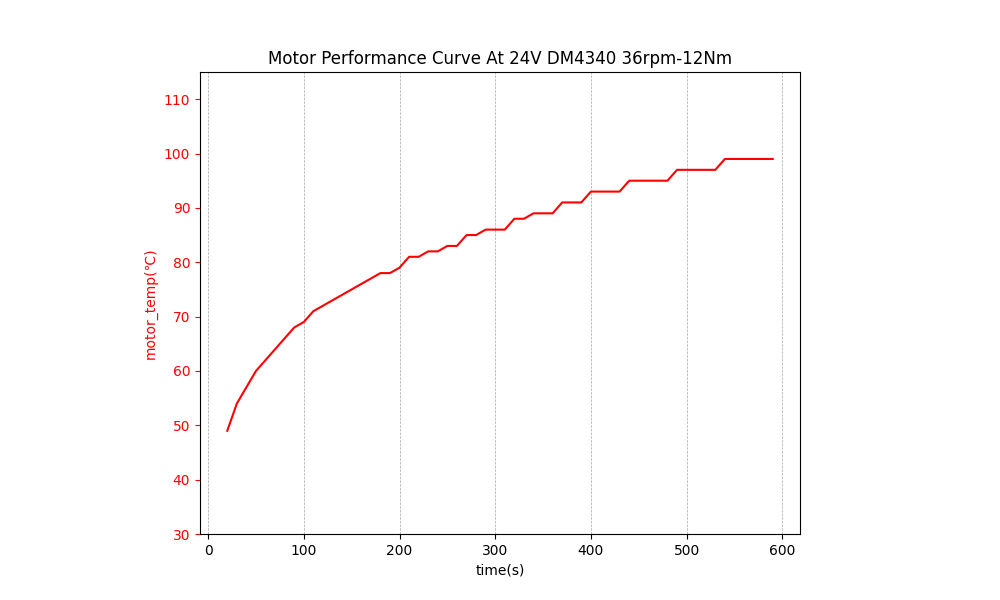
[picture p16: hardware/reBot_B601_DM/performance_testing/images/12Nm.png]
12Nm Load Curve


<p align="center">Damiao 43 Series Motor 12Nm Version Load Curve</p>

---

## 📝 Test Conclusions and Recommendations

### Usage Recommendations

1. **Recommended Working Conditions**
   - Load: < 1.5 kg
   - Working radius: < 70% reach (450 mm)
   - Motion speed: < 70% maximum speed
   - Ambient temperature: 15 °C ~ 35 °C

2. **Cooling Recommendations**
   - When working under high load for extended periods, adding active cooling is recommended
   - After 2 hours of continuous work, a 10~15 minute rest is recommended
   - Avoid direct sunlight and use in enclosed spaces

---

## 🙋 Frequently Asked Questions (FAQ)

<details>
<summary><b>Q1: Will the manipulator's performance decrease in high-temperature environments?</b></summary>

Yes. When the ambient temperature exceeds 35 °C or the motor temperature exceeds 75 °C, it is recommended to reduce load and motion speed to ensure accuracy and lifespan. Continuous use in high temperatures is not recommended.

</details>

<details>
<summary><b>Q2: Is the test data applicable to all versions?</b></summary>

This test is based on the reBot Arm B601-DM equipped with **Damiao V4 version motors**. **V3 and earlier motor versions have performance differences**, so test data is for reference only.

</details>

---

## 📅 Update History

| Version | Date | Update Content | Author |
|---|---|---|---|
| v1.0 | 2026.04.01 | Initial version, releasing basic performance test data | SeeedStudio AI Robotics Team |

---

## 📞 Technical Support

If you have any questions related to performance testing, please feel free to contact us:

- **Technical Support**: yaohui.zhu@seeed.cc
- **Discord**: [Join Community](https://discord.gg/AbGuqJhDpQ)
- **Wiki**: [View Knowledge Base](https://wiki.seeedstudio.com/robotics_page/)

---

<p align="center">
  <strong>🤖 reBot-DevArm - Open Source Manipulator for Every Developer</strong>
</p>

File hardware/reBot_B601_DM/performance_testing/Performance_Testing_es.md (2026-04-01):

# 🧪 Referencia de Pruebas de Rendimiento Físico reBot-DevArm

<p align="center">
  reBot-DevArm Banner
</p>

<p align="center">
  <strong>
    <a href="./Performance_Testing_zh.md">简体中文</a> &nbsp;|&nbsp;
    <a href="./Performance_Testing.md">English</a> &nbsp;|&nbsp;
    <a href="./Performance_Testing_JP.md">日本語</a>&nbsp;|&nbsp;
    <a href="./Performance_Testing_Fr.md">français</a>&nbsp;|&nbsp;
    <a href="./Performance_Testing_es.md">Español</a>
  </strong>
</p>

> [!NOTE]
> Este documento proporciona datos de referencia de pruebas de rendimiento para el brazo robótico reBot Arm B601-DM en condiciones de trabajo normales y extremas.

> [!WARNING]
> **Aviso de Diferencia de Versión**: Esta prueba se basa en el reBot Arm B601-DM equipado con **motores Damiao versión V4**. **Las versiones V3 y anteriores de los motores tienen diferencias de rendimiento**. Los datos de prueba son solo para referencia; el rendimiento real debe verificarse mediante pruebas.

---

## 💡 Resumen Rápido

**Motivo de Terminación de las Pruebas**: Todas las pruebas se terminaron debido a la **protección por sobrecalentamiento del motor 2 (articulación del brazo superior)**, no por fallo de la estructura mecánica.

**Prueba de Movimiento Dinámico** (Duración de un ciclo de movimiento: 5s estándar, movimiento de vaivén):

| Rango de Alcance | Carga | Duración | Motivo de Terminación |
|---|---|---|---|
| 5%~70% del Alcance Nominal | 1.5 kg | > 2 h | Temperatura del motor 2 alcanzó 90℃ |
| 5%~70% del Alcance Nominal | 2.5 kg | 40 min | Protección por sobrecalentamiento del motor 2 |
| 5%~100% del Alcance Nominal | 1.5 kg | 45 min | Protección por sobrecalentamiento del motor 2 |

**Prueba de Mantenimiento Estático**:

| Posición de Alcance | Carga | Duración | Motivo de Terminación |
|---|---|---|---|
| 70% del Alcance Nominal | 1.5 kg | 18 min | Protección por sobrecalentamiento del motor 2 |
| 100% del Alcance Nominal | 1.5 kg | 3 min | Protección por sobrecalentamiento del motor 2 |

> 👉 **Conclusión Clave**: La resistencia estructural del manipulador es suficiente. La terminación de las pruebas se debió a la **protección por sobrecalentamiento del motor 2**. La carga de trabajo recomendada es de **1.5 kg o menos**, el alcance de trabajo recomendado es **menor al 70%**, y se recomienda agregar medidas de refrigeración activa.

---

## 📋 Tabla de Contenidos

- [⚡ Prueba de Rendimiento en Condiciones Extremas](#-prueba-de-rendimiento-en-condiciones-extremas)
- [📈 Curva de Carga Oficial](#-curva-de-carga-oficial)
- [📝 Conclusiones y Recomendaciones de las Pruebas](#-conclusiones-y-recomendaciones-de-las-pruebas)
- [🙋 Preguntas Frecuentes (FAQ)](#-preguntas-frecuentes-faq)
- [📅 Historial de Actualizaciones](#-historial-de-actualizaciones)
- [📞 Soporte Técnico](#-soporte-técnico)

---

## ⚡ Prueba de Rendimiento en Condiciones Extremas

### Condiciones de la Prueba

**Prueba de Movimiento Dinámico**:
- Duración de un ciclo de movimiento: 5 s
- Modo de movimiento: Movimiento de vaivén
- Rango de alcance de prueba: 5%~70% / 5%~100% del alcance nominal

**Prueba de Mantenimiento Estático**:
- Postura de prueba: Mantenimiento de carga en postura estática
- Alcance de prueba: 70% / 100% del alcance nominal

### Resultados de las Pruebas

#### 1. Prueba de Movimiento Dinámico

| Posición de Prueba | Carga (kg) | Duración Máxima | Motivo de Terminación |
|---|---|---|---|
| Alcance 5%~70% | 1.5 | > 2 h | Protección por sobrecalentamiento del motor 2 |
| Alcance 5%~70% | 2.5 | 40 min | Protección por sobrecalentamiento del motor 2 |
| Alcance 5%~100% | 1.5 | 45 min | Protección por sobrecalentamiento del motor 2 |

#### 2. Prueba de Mantenimiento Estático

| Posición de Prueba | Carga (kg) | Duración Máxima | Motivo de Terminación |
|---|---|---|---|
| Alcance 70% | 1.5 | 18 min | Protección por sobrecalentamiento del motor 2 |
| Alcance 100% | 1.5 | 3 min | Protección por sobrecalentamiento del motor 2 |

---

## 📈 Curva de Carga Oficial

Curva de Carga 12Nm

<p align="center">Curva de Carga del Motor Serie Damiao 43 Versión 12Nm</p>

---

## 📝 Conclusiones y Recomendaciones de las Pruebas

### Recomendaciones de Uso

1. **Condiciones de Trabajo Recomendadas**
   - Carga: < 1.5 kg
   - Radio de trabajo: < 70% del alcance (450 mm)
   - Velocidad de movimiento: < 70% de la velocidad máxima
   - Temperatura ambiente: 15 °C ~ 35 °C

2. **Recomendaciones de Refrigeración**
   - Cuando se trabaje bajo carga elevada durante períodos prolongados, se recomienda agregar refrigeración activa
   - Después de 2 horas de trabajo continuo, se recomienda un descanso de 10~15 minutos
   - Evite la luz solar directa y el uso en espacios cerrados

---

## 🙋 Preguntas Frecuentes (FAQ)

<details>
<summary><b>P1: ¿El rendimiento del manipulador disminuye en ambientes de alta temperatura?</b></summary>

Sí. Cuando la temperatura ambiente supera los 35 °C o la temperatura del motor supera los 75 °C, se recomienda reducir la carga y la velocidad de movimiento para garantizar la precisión y la vida útil. No se recomienda el uso continuo en altas temperaturas.

</details>

<details>
<summary><b>P2: ¿Los datos de prueba son aplicables a todas las versiones?</b></summary>

Esta prueba se basa en el reBot Arm B601-DM equipado con **motores Damiao versión V4**. **Las versiones V3 y anteriores de los motores tienen diferencias de rendimiento**, por lo que los datos de prueba son solo para referencia.

</details>

---

## 📅 Historial de Actualizaciones

| Versión | Fecha | Contenido de la Actualización | Autor |
|---|---|---|---|
| v1.0 | 2026.04.01 | Versión inicial, publicación de datos básicos de pruebas de rendimiento | SeeedStudio AI Robotics Team |

---

## 📞 Soporte Técnico

Si tiene alguna pregunta relacionada con las pruebas de rendimiento, no dude en contactarnos:

- **Soporte Técnico**: yaohui.zhu@seeed.cc
- **Discord**: [Unirse a la Comunidad](https://discord.gg/AbGuqJhDpQ)
- **Wiki**: [Ver Base de Conocimientos](https://wiki.seeedstudio.com/robotics_page/)

---

<p align="center">
  <strong>🤖 reBot-DevArm - Manipulador de Código Abierto para Cada Desarrollador</strong>
</p>

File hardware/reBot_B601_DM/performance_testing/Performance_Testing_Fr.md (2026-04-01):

# 🧪 Référence de Test de Performance Physique reBot-DevArm

<p align="center">
  reBot-DevArm Banner
</p>

<p align="center">
  <strong>
    <a href="./Performance_Testing_zh.md">简体中文</a> &nbsp;|&nbsp;
    <a href="./Performance_Testing.md">English</a> &nbsp;|&nbsp;
    <a href="./Performance_Testing_JP.md">日本語</a>&nbsp;|&nbsp;
    <a href="./Performance_Testing_Fr.md">français</a>&nbsp;|&nbsp;
    <a href="./Performance_Testing_es.md">Español</a>
  </strong>
</p>

> [!NOTE]
> Ce document fournit des données de référence de test de performance pour le bras robotique reBot Arm B601-DM dans des conditions de travail normales et extrêmes.

> [!WARNING]
> **Avis de Différence de Version**: Ce test est basé sur le reBot Arm B601-DM équipé de **moteurs Damiao version V4**. **Les versions V3 et antérieures des moteurs présentent des différences de performance**. Les données de test sont fournies à titre indicatif ; veuillez vérifier les performances réelles par des tests.

---

## 💡 Résumé Rapide

**Raison d'Arrêt des Tests**: Tous les tests ont été arrêtés en raison de la **protection contre la surchauffe du moteur 2 (articulation du bras supérieur)**, et non d'une défaillance de la structure mécanique.

**Test de Mouvement Dynamique** (Durée d'un cycle de mouvement : 5s standard, mouvement de va-et-vient) :

| Plage de Portée | Charge | Durée | Raison d'Arrêt |
|---|---|---|---|
| 5%~70% de la Portée Nominale | 1.5 kg | > 2 h | Température du moteur 2 à 90℃ |
| 5%~70% de la Portée Nominale | 2.5 kg | 40 min | Protection contre la surchauffe du moteur 2 |
| 5%~100% de la Portée Nominale | 1.5 kg | 45 min | Protection contre la surchauffe du moteur 2 |

**Test de Maintien Statique**:

| Position de Portée | Charge | Durée | Raison d'Arrêt |
|---|---|---|---|
| 70% de la Portée Nominale | 1.5 kg | 18 min | Protection contre la surchauffe du moteur 2 |
| 100% de la Portée Nominale | 1.5 kg | 3 min | Protection contre la surchauffe du moteur 2 |

> 👉 **Conclusion Clé**: La résistance structurelle du manipulateur est suffisante. L'arrêt des tests était dû à la **protection contre la surchauffe du moteur 2**. La charge de travail recommandée est de **1.5 kg ou moins**, la portée de travail recommandée est **inférieure à 70%**, et il est conseillé d'ajouter des mesures de refroidissement actif.

---

## 📋 Table des Matières

- [⚡ Test de Performance en Conditions Extrêmes](#-test-de-performance-en-conditions-extrêmes)
- [📈 Courbe de Charge Officielle](#-courbe-de-charge-officielle)
- [📝 Conclusions et Recommandations](#-conclusions-et-recommandations)
- [🙋 Questions Fréquemment Posées (FAQ)](#-questions-fréquemment-posées-faq)
- [📅 Historique des Mises à Jour](#-historique-des-mises-à-jour)
- [📞 Support Technique](#-support-technique)

---

## ⚡ Test de Performance en Conditions Extrêmes

### Conditions de Test

**Test de Mouvement Dynamique**:
- Durée d'un cycle de mouvement : 5 s
- Mode de mouvement : Mouvement de va-et-vient
- Plage de portée de test : 5%~70% / 5%~100% de la portée nominale

**Test de Maintien Statique**:
- Position de test : Maintien de charge en position statique
- Portée de test : 70% / 100% de la portée nominale

### Résultats des Tests

#### 1. Test de Mouvement Dynamique

| Position de Test | Charge (kg) | Durée Maximale | Raison d'Arrêt |
|---|---|---|---|
| Portée 5%~70% | 1.5 | > 2 h | Protection contre la surchauffe du moteur 2 |
| Portée 5%~70% | 2.5 | 40 min | Protection contre la surchauffe du moteur 2 |
| Portée 5%~100% | 1.5 | 45 min | Protection contre la surchauffe du moteur 2 |

#### 2. Test de Maintien Statique

| Position de Test | Charge (kg) | Durée Maximale | Raison d'Arrêt |
|---|---|---|---|
| Portée 70% | 1.5 | 18 min | Protection contre la surchauffe du moteur 2 |
| Portée 100% | 1.5 | 3 min | Protection contre la surchauffe du moteur 2 |

---

## 📈 Courbe de Charge Officielle

Courbe de Charge 12Nm

<p align="center">Courbe de Charge du Moteur Série Damiao 43 Version 12Nm</p>

---

## 📝 Conclusions et Recommandations

### Recommandations d'Utilisation

1. **Conditions de Travail Recommandées**
   - Charge : < 1.5 kg
   - Rayon de travail : < 70% de la portée (450 mm)
   - Vitesse de mouvement : < 70% de la vitesse maximale
   - Température ambiante : 15 °C ~ 35 °C

2. **Recommandations de Refroidissement**
   - Lors d'un travail prolongé sous charge élevée, il est recommandé d'ajouter un refroidissement actif
   - Après 2 heures de travail continu, une pause de 10~15 minutes est recommandée
   - Évitez l'exposition directe au soleil et l'utilisation dans des espaces fermés

---

## 🙋 Questions Fréquemment Posées (FAQ)

<details>
<summary><b>Q1 : Les performances du manipulateur diminuent-elles dans des environnements à haute température ?</b></summary>

Oui. Lorsque la température ambiante dépasse 35 °C ou que la température du moteur dépasse 75 °C, il est recommandé de réduire la charge et la vitesse de mouvement pour garantir la précision et la durée de vie. L'utilisation continue à haute température n'est pas recommandée.

</details>

<details>
<summary><b>Q2 : Les données de test sont-elles applicables à toutes les versions ?</b></summary>

Ce test est basé sur le reBot Arm B601-DM équipé de **moteurs Damiao version V4**. **Les versions V3 et antérieures des moteurs présentent des différences de performance**, les données de test sont donc fournies à titre indicatif.

</details>

---

## 📅 Historique des Mises à Jour

| Version | Date | Contenu de la Mise à Jour | Auteur |
|---|---|---|---|
| v1.0 | 2026.04.01 | Version initiale, publication des données de test de performance de base | SeeedStudio AI Robotics Team |

---

## 📞 Support Technique

Si vous avez des questions relatives aux tests de performance, n'hésitez pas à nous contacter :

- **Support Technique**: yaohui.zhu@seeed.cc
- **Discord**: [Rejoindre la Communauté](https://discord.gg/AbGuqJhDpQ)
- **Wiki**: [Consulter la Base de Connaissances](https://wiki.seeedstudio.com/robotics_page/)

---

<p align="center">
  <strong>🤖 reBot-DevArm - Manipulateur Open Source pour Chaque Développeur</strong>
</p>

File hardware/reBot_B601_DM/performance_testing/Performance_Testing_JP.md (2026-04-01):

# 🧪 reBot-DevArm 実機性能テストリファレンス

<p align="center">
  reBot-DevArm Banner
</p>

<p align="center">
  <strong>
    <a href="./Performance_Testing_zh.md">简体中文</a> &nbsp;|&nbsp;
    <a href="./Performance_Testing.md">English</a> &nbsp;|&nbsp;
    <a href="./Performance_Testing_JP.md">日本語</a>&nbsp;|&nbsp;
    <a href="./Performance_Testing_Fr.md">français</a>&nbsp;|&nbsp;
    <a href="./Performance_Testing_es.md">Español</a>
  </strong>
</p>

> [!NOTE]
> このドキュメントは、通常および極限の作業条件における reBot Arm B601-DM の性能テストデータリファレンスを提供します。

> [!WARNING]
> **バージョン差異のお知らせ**: このテストは、**Damiao V4 バージョンモーター**を搭載した reBot Arm B601-DM に基づいています。**V3 およびそれ以前のモーターバージョンは性能が異なります**。テストデータは参考用であり、実際の性能は実測为准としてください。

---

## 💡 クイックサマリー

**テスト終了理由**: すべてのテストは、**2 番モーター（大臂関節）の過熱保護**により終了しました。機械構造の故障ではありません。

**動的動作テスト**（単一動作時間 5 秒基準、往復動作）:

| リーチ範囲 | 負荷 | 持続時間 | 終了理由 |
|---|---|---|---|
| 5%~70% 定格リーチ | 1.5 kg | > 2 h | 2 番モーター温度 90℃到達 |
| 5%~70% 定格リーチ | 2.5 kg | 40 min | 2 番モーター過熱保護 |
| 5%~100% 定格リーチ | 1.5 kg | 45 min | 2 番モーター過熱保護 |

**静的保持テスト**:

| リーチ位置 | 負荷 | 持続時間 | 終了理由 |
|---|---|---|---|
| 70% 定格リーチ | 1.5 kg | 18 min | 2 番モーター過熱保護 |
| 100% 定格リーチ | 1.5 kg | 3 min | 2 番モーター過熱保護 |

> 👉 **主要結論**: マニピュレータの構造強度は十分です。テスト終了の理由は**2 番モーターの過熱保護**です。推奨作業負荷は**1.5 kg 以下**、作業リーチは**70% 未満**を推奨し、アクティブ冷却措置の追加を推奨します。

---

## 📋 目次

- [⚡ 極限作業性能テスト](#-極限作業性能テスト)
- [📈 公式負荷曲線](#-公式負荷曲線)
- [📝 テスト結論と推奨事項](#-テスト結論と推奨事項)
- [🙋 よくある質問 (FAQ)](#-よくある質問-faq)
- [📅 更新履歴](#-更新履歴)
- [📞 テクニカルサポート](#-テクニカルサポート)

---

## ⚡ 極限作業性能テスト

### テスト条件

**動的動作テスト**:
- 単一動作時間：5 秒
- 動作モード：往復動作
- テストリーチ範囲：5%~70% / 5%~100% 定格リーチ

**静的保持テスト**:
- テスト姿勢：静止姿勢負荷保持
- テストリーチ：70% / 100% 定格リーチ

### テスト結果

#### 1. 動的動作テスト

| テスト位置 | 負荷 (kg) | 最大持続時間 | 終了理由 |
|---|---|---|---|
| リーチ 5%~70% | 1.5 | > 2 h | 2 番モーター過熱保護 |
| リーチ 5%~70% | 2.5 | 40 min | 2 番モーター過熱保護 |
| リーチ 5%~100% | 1.5 | 45 min | 2 番モーター過熱保護 |

#### 2. 静的保持テスト

| テスト位置 | 負荷 (kg) | 最大持続時間 | 終了理由 |
|---|---|---|---|
| リーチ 70% | 1.5 | 18 min | 2 番モーター過熱保護 |
| リーチ 100% | 1.5 | 3 min | 2 番モーター過熱保護 |

---

## 📈 公式負荷曲線

12Nm 負荷曲線

<p align="center">Damiao 43 シリーズモーター 12Nm バージョン負荷曲線</p>

---

## 📝 テスト結論と推奨事項

### 使用推奨事項

1. **推奨作業条件**
   - 負荷：< 1.5 kg
   - 作業半径：< 70% リーチ（450 mm）
   - 動作速度：< 70% 最大速度
   - 環境温度：15 °C ~ 35 °C

2. **冷却推奨事項**
   - 長時間高負荷作業時は、アクティブ冷却の追加を推奨
   - 2 時間の連続作業後、10~15 分の休憩を推奨
   - 直射日光や密閉空間での使用を避けてください

---

## 🙋 よくある質問 (FAQ)

<details>
<summary><b>Q1: 高温環境下ではマニピュレータの性能は低下しますか？</b></summary>

はい。環境温度が 35 °C を超えるか、モーター温度が 75 °C を超える場合、精度と寿命を確保するために負荷と動作速度を低下させることを推奨します。高温下での継続的な使用は推奨しません。

</details>

<details>
<summary><b>Q2: テストデータはすべてのバージョンに適用されますか？</b></summary>

このテストは、**Damiao V4 バージョンモーター**を搭載した reBot Arm B601-DM に基づいています。**V3 およびそれ以前のモーターバージョンは性能が異なります**。テストデータは参考用です。

</details>

---

## 📅 更新履歴

| バージョン | 日付 | 更新内容 | 作成者 |
|---|---|---|---|
| v1.0 | 2026.04.01 | 初期バージョン、基本性能テストデータ公開 | SeeedStudio AI Robotics Team |

---

## 📞 テクニカルサポート

性能テストに関するご質問がありましたら、お気軽にお問い合わせください：

- **テクニカルサポート**: yaohui.zhu@seeed.cc
- **Discord**: [コミュニティに参加](https://discord.gg/AbGuqJhDpQ)
- **Wiki**: [ナレッジベースを表示](https://wiki.seeedstudio.com/robotics_page/)

---

<p align="center">
  <strong>🤖 reBot-DevArm - すべての開発者のためのオープンソースマニピュレータ</strong>
</p>

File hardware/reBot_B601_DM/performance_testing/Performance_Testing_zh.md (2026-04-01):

# 🧪 reBot-DevArm 真机性能测试参考

<p align="center">
  reBot-DevArm Banner
</p>

<p align="center">
  <strong>
    <a href="./Performance_Testing_zh.md">简体中文</a> &nbsp;|&nbsp;
    <a href="./Performance_Testing.md">English</a> &nbsp;|&nbsp;
    <a href="./Performance_Testing_JP.md">日本語</a>&nbsp;|&nbsp;
    <a href="./Performance_Testing_Fr.md">français</a>&nbsp;|&nbsp;
    <a href="./Performance_Testing_es.md">Español</a>
  </strong>
</p>

> [!NOTE]
> 本文档提供 reBot Arm B601-DM 机械臂在常规工作及极限工作条件下的性能测试数据参考。

> [!WARNING]
> **版本差异提示**：本测试基于搭载 **达妙 V4 版本电机** 的 reBot Arm B601-DM。**V3 及之前版本的电机性能存在差异**，测试数据仅供参考，实际性能请以实测为准。

---

## 💡 省流总结

**测试终止原因**：所有测试均因 **2 号电机（大臂关节）过热保护** 而终止，非机械结构失效。

**动态运动测试**（单组动作时长 5s 标准，往复运动）：

| 臂展区间 | 负载 | 持续时间 | 终止原因 |
|---|---|---|---|
| 5%~70% 额定臂长 | 1.5 kg | > 2 h | 2 号电机温度达 90℃ |
| 5%~70% 额定臂长 | 2.5 kg | 40 min | 2 号电机过热保护 |
| 5%~100% 额定臂长 | 1.5 kg | 45 min | 2 号电机过热保护 |

**静止保持测试**：

| 臂展位置 | 负载 | 持续时间 | 终止原因 |
|---|---|---|---|
| 70% 额定臂长 | 1.5 kg | 18 min | 2 号电机过热保护 |
| 100% 额定臂长 | 1.5 kg | 3 min | 2 号电机过热保护 |

> 👉 **核心结论**：机械臂结构强度充足，测试终止原因为 **2 号电机过热保护**。推荐工作负载 **1.5 kg 及以下**，工作臂展建议 **小于 70%**，并建议增加主动散热措施。

---

## 📋 目录

- [⚡ 极限工作性能测试](#-极限工作性能测试)
- [📈 官方负载曲线](#-官方负载曲线)
- [📝 测试结论与建议](#-测试结论与建议)
- [🙋 常见问题 (FAQ)](#-常见问题-faq)
- [📅 更新记录](#-更新记录)
- [📞 技术支持](#-技术支持)

---

## ⚡ 极限工作性能测试

### 测试条件

**动态运动测试**：
- 单组动作时长：5 s
- 运动模式：往复运动
- 测试臂展区间：5%~70% / 5%~100% 额定臂长

**静止保持测试**：
- 测试姿态：静止姿态负载静置
- 测试臂展：70% / 100% 额定臂长

### 测试结果

#### 1. 动态运动测试

| 测试位置 | 负载 (kg) | 最长持续时间 | 终止原因 |
|---|---|---|---|
| 臂展 5%~70% | 1.5 | > 2 h | 2 号电机过热保护 |
| 臂展 5%~70% | 2.5 | 40 min | 2 号电机过热保护 |
| 臂展 5%~100% | 1.5 | 45 min | 2 号电机过热保护 |

#### 2. 静止保持测试

| 测试位置 | 负载 (kg) | 最长持续时间 | 终止原因 |
|---|---|---|---|
| 臂展 70% | 1.5 | 18 min | 2 号电机过热保护 |
| 臂展 100% | 1.5 | 3 min | 2 号电机过热保护 |

---

## 📈 官方负载曲线

12Nm 负载曲线图

<p align="center">达妙 43 系列电机 12Nm 版本负载曲线</p>

---

## 📝 测试结论与建议

### 使用建议

1. **推荐工作条件**
   - 负载：< 1.5 kg
   - 工作半径：< 70% 臂展（450 mm）
   - 运动速度：< 70% 最大速度
   - 环境温度：15 °C ~ 35 °C

2. **散热建议**
   - 长时间高负载工作时，建议增加主动散热
   - 连续工作 2 小时后，建议休息 10~15 分钟
   - 避免阳光直射和密闭空间使用

---

## 🙋 常见问题 (FAQ)

<details>
<summary><b>Q1: 机械臂在高温环境下性能会下降吗？</b></summary>

是的。当环境温度超过 35 °C 或电机温度超过 75 °C 时，建议降低负载和运动速度以保证精度和寿命。不建议在高温下持续使用。

</details>

<details>
<summary><b>Q2: 测试数据是否适用于所有版本？</b></summary>

本测试基于搭载 **达妙 V4 版本电机** 的 reBot Arm B601-DM。**V3 及之前版本的电机性能存在差异**，测试数据仅供参考。

</details>

---

## 📅 更新记录

| 版本 | 日期 | 更新内容 | 作者 |
|---|---|---|---|
| v1.0 | 2026.04.01 | 初始版本，发布基础性能测试数据 | SeeedStudio AI Robotics Team |

---

## 📞 技术支持

如有任何性能测试相关问题，欢迎联系我们：

- **技术支持**: yaohui.zhu@seeed.cc
- **Discord**: [加入社区](https://discord.gg/AbGuqJhDpQ)
- **Wiki**: [查看知识库](https://wiki.seeedstudio.com/robotics_page/)

---

<p align="center">
  <strong>🤖 reBot-DevArm - 为每个开发者开源的机械臂</strong>
</p>

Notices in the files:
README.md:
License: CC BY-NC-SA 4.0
